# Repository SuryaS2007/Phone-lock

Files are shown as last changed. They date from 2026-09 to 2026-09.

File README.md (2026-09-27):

# Focus Lock

Focus Lock is an ESP32-powered phone lock and active-study timer. RFID tags embedded in physical shells identify saved study durations. The website changes the duration associated with each shell. After scanning a shell, lifting the pencil from its fixed crab-claw rest locks the phone drawer and starts the countdown; returning the pencil pauses it. Reaching zero unlocks the drawer.

## Final prototype flow

```text
Scan RFID shell
-> ESP32 loads that shell's saved duration
-> optionally change/save its duration on the website
-> place pencil on the fixed claws
-> lift pencil
-> drawer locks, buzzer sounds, countdown starts
-> return pencil to pause
-> lift it to resume
-> countdown reaches zero
-> drawer unlocks and buzzer sounds
```

RFID UIDs are hardware identifiers and are not rewritten. The website stores an editable UID-to-duration association in ESP32 nonvolatile memory.

## Hardware roles

- Generic 30-pin ESP32 DevKit V1: controller, Wi-Fi access point, API, timer, and website host.
- Two VL53L0X sensors: detect whether the pencil rests across the stationary claws.
- RC522: reads the RFID tag inside a shell and selects its duration.
- SG90 on GPIO26: locks and unlocks the phone drawer.
- SG90 on GPIO25: optionally sways the crab while active study time is counting.
- TM1637 on GPIO14/GPIO13: physical countdown only.
- LCD1602 at I2C address `0x27`: displays the crab-eye graphic.
- Passive buzzer on GPIO17: start and completion sounds.
- There is no phone-box sensor, reward system, or shell dispenser.

Servo features, shake motion, and buzzer output are disabled by default until their hardware is safely powered and calibrated.

## Website

While connected to the ESP32 `Focus-Lock` access point, open `/servo-test.html` for the development-only lock-servo calibration controls. The page supports direct position commands, repeated sequences, emergency detach, and persistent lock/unlock angle settings.

The beach-themed site is served by the ESP32 at `http://192.168.4.1` on its open `Focus-Lock` Wi-Fi network. It displays the timer and state, shows the last scanned shell UID, edits that shell's duration, provides short developer demos, and plays a user-selected local music file.

## Main API

- `GET /status`: timer, pencil, RFID, sensor, servo, and selected-shell status.
- `GET /shells`: saved shell UID-to-duration mappings.
- `POST /shell`: save `{ "uid": "A1B2C3D4", "duration": 1800 }`.
- `POST /start`: developer demo duration in seconds.
- `POST /reset`: cancel and safely unlock.

Times are seconds. Up to 12 shell mappings and durations up to eight hours are supported.

## PlatformIO

```ini
platform = espressif32@6.12.0
board = esp32doit-devkit-v1
framework = arduino
```

Use PlatformIO **Upload** for firmware and **Upload Filesystem Image** for the website. The build script copies the browser assets into LittleFS automatically.

## Important files

```text
platformio.ini                      PlatformIO environment and libraries
firmware/src/main.cpp               ESP32 firmware
firmware/include/PinConfig.h        GPIO allocation
firmware/include/HardwareConfig.h   calibration and feature flags
firmware/scripts/sync_web.py        browser-to-LittleFS asset sync
index.html and src/                 website
HARDWARE_TRAINING.md                wiring and calibration procedure
PROJECT_LOG.md                      decisions and change history
```

## Power warning

SG90 servos require 4.8-6 V; regulated 5 V is the target. Do not power them from ESP32 3.3 V. The rectangular 9 V battery and breadboard regulator are not a dependable servo source. During development, power the ESP32 over USB and use an adequate regulated 5 V servo supply with its ground connected to ESP32 ground.

If the LCD1602 I2C backpack is powered at 5 V, verify that its SDA/SCL pull-ups do not expose ESP32 pins to 5 V; use 3.3 V operation or proper level shifting as required.

Apply the same caution to the TM1637 module: verify whether the actual board operates at 3.3 V or add suitable level shifting before using a 5 V-powered module with 3.3 V ESP32 GPIO.

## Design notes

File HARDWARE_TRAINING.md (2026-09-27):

# Focus Lock hardware training

Work through these stages in order. Keep `SERVO_ENABLED`, `SHAKE_SERVO_ENABLED`, and `BUZZER_ENABLED` false until each component is tested safely.

## 1. Power safely

```text
Computer USB -> ESP32
ESP32 3V3 -> VL53L0X and RC522 power
Regulated 5V -> SG90 red wires
5V supply ground -> servo grounds AND ESP32 GND
```

Do not use the rectangular 9 V battery as the dependable servo source. SG90 voltage must remain within 4.8-6 V; use regulated 5 V.

## 2. Wire the pencil sensors

```text
Both SDA    -> GPIO21
Both SCL    -> GPIO22
Both VIN    -> 3V3
Both GND    -> GND
Left XSHUT  -> GPIO32
Right XSHUT -> GPIO33
```

The claws do not move. Mount one sensor under each side of the pencil rest. Firmware assigns the sensors I2C addresses `0x30` and `0x31` after every boot.

## 3. Upload the safe base

1. Build and upload the `esp32doit-devkit-v1` environment.
2. Run **Upload Filesystem Image**.
3. Open Serial Monitor at 115200 baud.
4. Confirm both pencil sensors and RC522 initialize.

## 4. Calibrate pencil presence

Serial Monitor prints:

```text
PENCIL_RAW left=42 right=45 removed=false
```

Record ten readings with the pencil resting and ten with it removed. Put the halfway values in `HardwareConfig.h`:

```cpp
LEFT_PENCIL_THRESHOLD_MM = ...;
RIGHT_PENCIL_THRESHOLD_MM = ...;
```

If readings are lower when the pencil is present, keep `PENCIL_PRESENT_WHEN_DISTANCE_LESS = true`; otherwise change it to `false`.

The firmware considers the pencil removed only when both sensors report it absent for at least 350 ms. Returning it over either sensor pauses the timer.

## 5. Train RFID shell durations

Wire the RC522 using the pins in `PinConfig.h`, restart, and connect to the open `Focus-Lock` Wi-Fi network.

1. Open `http://192.168.4.1`.
2. Scan one shell tag.
3. Confirm its UID appears on the website.
4. Enter a duration and select **Save shell**.
5. Scan another shell and give it a different duration.
6. Restart the ESP32 and verify each saved duration remains.

The tag UID is not changed; only its stored duration association changes.

## 6. Test the timer without servos

1. Scan a configured shell or choose a 10-second demo.
2. Rest the pencil across the claws.
3. Lift the pencil and confirm the countdown begins.
4. Return it and confirm the countdown pauses.
5. Lift it again and confirm the timer reaches zero.
6. Confirm the TM1637 shows remaining `MM:SS`.

Verify the TM1637 module's logic voltage before connection. Prefer 3.3 V operation if the module is reliable there; otherwise use appropriate level shifting for its CLK/DIO signals.

## 7. Calibrate the lock SG90

For an unloaded bench test, `SERVO_CYCLE_TEST_MODE` slowly moves the lock servo on GPIO26 from 90 degrees to 0 degrees and back to 90 degrees three times, then detaches the servo signal. Physical clockwise/counterclockwise direction depends on servo mounting. Keep this mode disabled during normal operation and never run it against a mechanical hard stop.

`SERVO_SWIFT_TEST_MODE` sends direct positions without intermediate steps. The current physical 270 -> 180 -> 270 reference maps to servo commands 90 -> 0 -> 90. All executed tests are recorded in `SERVO_TEST_RUNS.md`.

For normal calibration, connect to the `Focus-Lock` Wi-Fi network and open `http://192.168.4.1/servo-test.html`. The page can move to a direct angle, run repeated position sequences, stop and detach the servo, and save the selected angle as the locked or unlocked position. Saved angles persist in ESP32 nonvolatile memory. Servo controls are rejected while a study session is armed or running.

Remove the horn or disconnect the linkage. Use a regulated 5 V supply with common ground. Set:

```cpp
SERVO_ENABLED = false;
SERVO_CALIBRATION_MODE = true;
```

Upload and send `+` or `-` in Serial Monitor to move five degrees at a time. Record safe unlock and lock angles, then set:

```cpp
SERVO_UNLOCK_ANGLE = ...;
SERVO_LOCK_ANGLE = ...;
SERVO_CALIBRATION_MODE = false;
SERVO_ENABLED = true;
```

Stop immediately if the servo stalls, buzzes continuously, heats up, or pushes against a hard stop.

## 8. Add buzzer and shake servo

The buzzer code assumes a passive buzzer on GPIO17. After verifying its type and wiring, set `BUZZER_ENABLED = true`.

The second SG90 uses GPIO25. Calibrate safe left, center, and right angles before setting `SHAKE_SERVO_ENABLED = true`. When enabled, it sways only during `LOCKED_STUDYING` and centers while paused or complete.

## 9. LCD1602 eyes

The base assumes an I2C-backpack LCD1602 at address `0x27` on GPIO21/GPIO22. If it does not respond, run an I2C scan; common alternatives include `0x3F`. Verify safe I2C logic voltage before using a 5 V backpack.

Connect the four I2C-backpack pins as follows:

| LCD1602 backpack | ESP32 |
| --- | --- |
| GND | GND |
| VCC | Safe supply for the specific backpack; verify its logic voltage |
| SDA | GPIO21 (shared with the VL53L0X sensors) |
| SCL | GPIO22 (shared with the VL53L0X sensors) |

The integrated firmware now animates center, left, right, blink, surprised, happy, and sleeping eyes. The expressions respond to the Focus Lock state: selecting a shell shows surprised eyes, a paused timer sleeps, active study uses the calm look/blink loop, and completion shows happy eyes.

Do not connect the LCD using the earlier six-wire prototype assignment `(23, 22, 21, 19, 18, 5)`. Those pins conflict with the RC522 and VL53L0X hardware. The main firmware uses the I2C backpack so the LCD shares only GPIO21/GPIO22.

## 10. Acceptance test

Repeat at least ten times:

```text
Scan shell -> duration loads -> pencil rests -> pencil lifts
-> lock and start sound -> countdown runs -> pencil returns
-> countdown pauses -> pencil lifts -> countdown completes
-> unlock and completion sound
```

Test with a nonvaluable object before placing a phone inside, and retain a manual release.

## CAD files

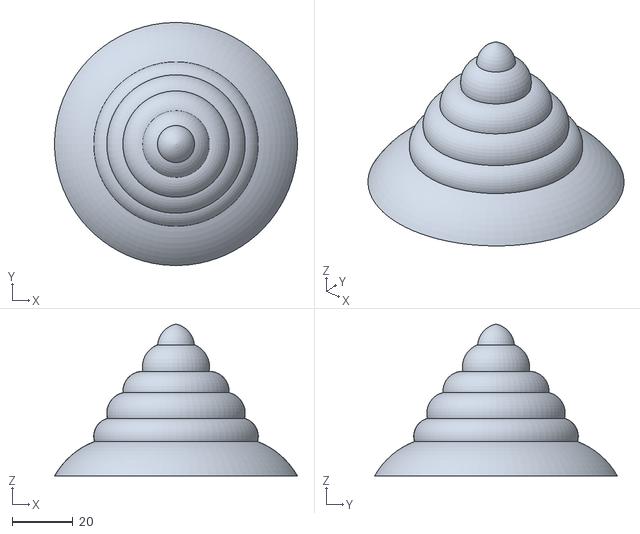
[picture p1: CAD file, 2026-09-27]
printable_stls/big_shell.STL
80.0 x 79.9 x 50.0

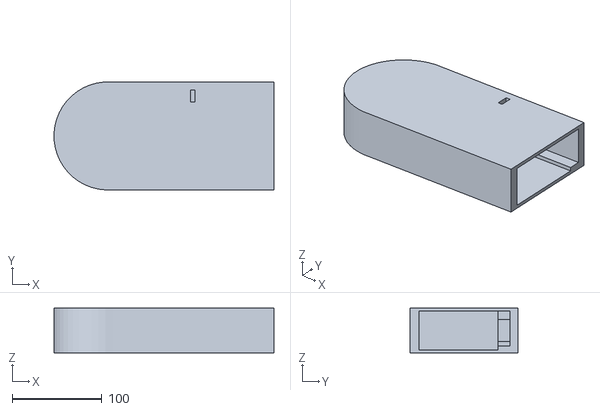
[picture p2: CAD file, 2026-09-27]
printable_stls/base_stand.STL
245.1 x 120.1 x 50.0

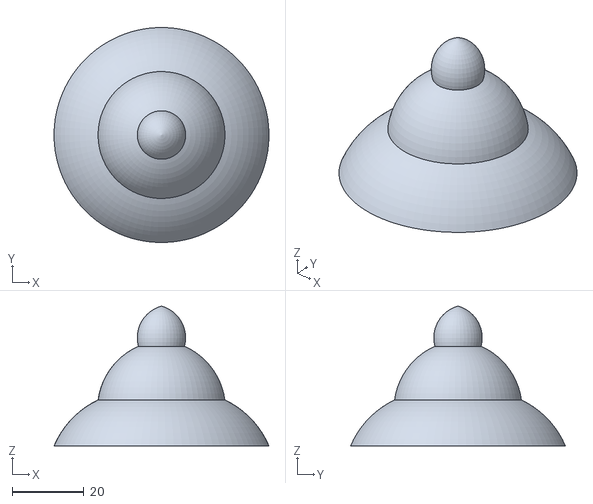
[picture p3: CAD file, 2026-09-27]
printable_stls/small_shell.STL
60.0 x 60.0 x 39.0

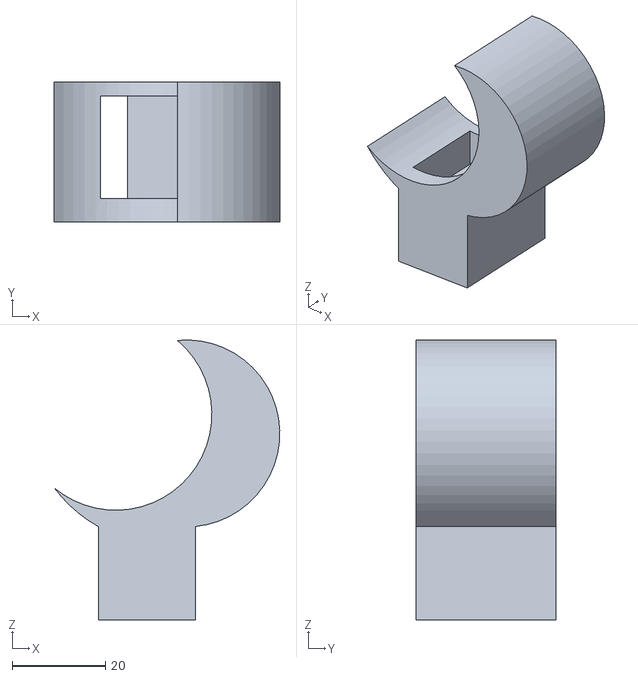
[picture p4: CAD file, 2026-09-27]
printable_stls/claw_arm.STL
48.2 x 30.0 x 59.9

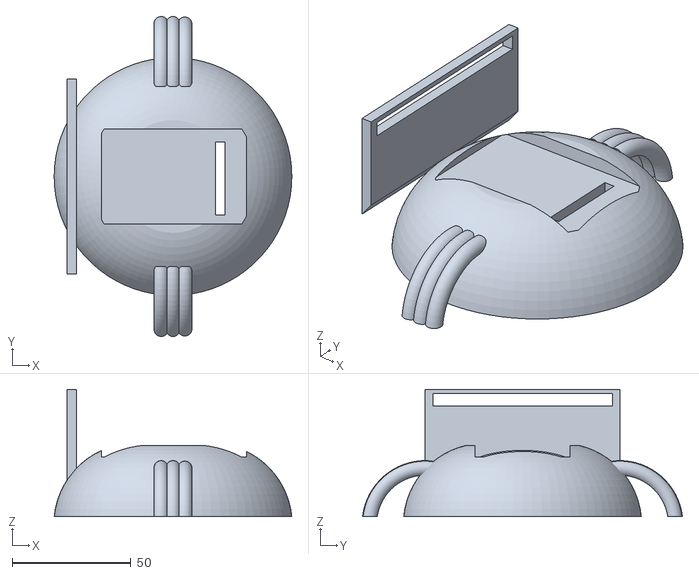
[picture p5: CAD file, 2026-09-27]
printable_stls/body_print.STL
100.0 x 134.6 x 53.5

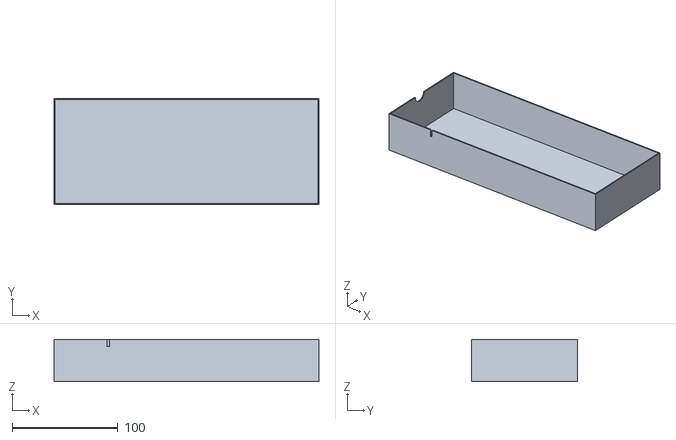
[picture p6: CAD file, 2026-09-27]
printable_stls/drawer_base.STL
250.0 x 100.0 x 40.0

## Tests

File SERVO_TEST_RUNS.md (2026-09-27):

# Focus Lock servo test runs

This file records physical lock-servo tests performed on GPIO26. The servo uses an external regulated 5 V supply with a ground shared with the ESP32.

## Angle notation

The SG90 control command accepts angles from 0 to 180 degrees. For the current mechanical orientation, the team's physical reference labels map as follows:

| Physical reference | Servo command |
| --- | ---: |
| 270 degrees | 90 degrees |
| 180 degrees | 0 degrees |

Physical clockwise/counterclockwise direction depends on which side of the servo is viewed and how its horn is installed.

## 2026-09-26 — Connection and small-movement test

- Board detected as a CP2102 device on COM4 after installing its Windows driver.
- Servo signal: GPIO26.
- Commands: 90 -> 95 -> 100 -> 105 -> 110 -> 105 -> 100 -> 95 -> 90 degrees.
- Result: upload and commands succeeded; user confirmed that the servo moved.
- Firmware was restored with calibration mode disabled.

## 2026-09-26 — Slow three-cycle test

- Commands: 90 -> 0 -> 90 degrees.
- Repetitions: three.
- Motion: smooth 1-degree steps with a 15 ms delay per step.
- End state: 90 degrees, followed by detaching the servo signal.
- Firmware upload completed and automatic test mode was disabled afterward.

## 2026-09-26 — Swift physical 270/180/270 test

- Physical sequence: 270 -> 180 -> 270 degrees.
- Servo command sequence: 90 -> 0 -> 90 degrees.
- Motion: direct position commands with no intermediate 1-degree steps.
- Result: firmware built and uploaded successfully; sequence executed once. Physical movement confirmation is pending from the user.
- Safe restoration: automatic swift test mode was disabled after execution and normal firmware was re-uploaded.

## Reusable browser test controller

- Page: `http://192.168.4.1/servo-test.html` while connected to `Focus-Lock` Wi-Fi.
- Supports direct positions, presets, repeated direct-position sequences, and emergency detach.
- Supports saving calibrated locked and unlocked angles in ESP32 nonvolatile memory.
- Test controls are blocked while a study session is armed or running.
- The page is controlled by `DEVELOPER_TOOLS_ENABLED` in `HardwareConfig.h`.

## 2026-09-26 — Direct firmware fallback test

- Reason: browser pages still reported offline, so the website was bypassed.
- Physical sequence: 270 -> 180 -> 270 degrees.
- Servo command sequence: 90 -> 0 -> 90 degrees on GPIO26.
- Motion: direct commands with no stepping.
- Firmware upload completed, the sequence ran once, and automatic test mode was disabled afterward.

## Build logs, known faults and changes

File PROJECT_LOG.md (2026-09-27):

# Focus Lock — Project Work Log

This document is the living record of work performed on **Focus Lock**. Update it whenever code, configuration, architecture, behavior, dependencies, documentation, or hardware integration changes.

## Project Goal

Focus Lock is a hackathon project built around an ESP32, two light sensors, and a servo-controlled phone drawer. A user chooses an active study-time goal, locks their phone, and earns access to it by studying. Active study time accumulates only while the pencil is picked up; putting the pencil down pauses the timer. Reaching the goal unlocks the phone.

The first milestone is a fully simulated software system. Real ESP32 sensor and servo behavior will replace the simulation later through a hardware abstraction layer.

## Required Core Flow

1. Phone inserted.
2. User starts a session.
3. Phone drawer locks.
4. Pencil picked up.
5. Active-study timer runs.
6. Pencil put down.
7. Timer pauses without resetting.
8. Pencil picked up again.
9. Timer continues from its accumulated value.
10. Active-study goal is reached.
11. Phone drawer unlocks.

## Scope

### In scope

- A clean, simple web frontend.
- Simulated phone, pencil, and servo controls.
- Session states: `IDLE`, `READY`, `LOCKED_PAUSED`, `LOCKED_STUDYING`, and `COMPLETE`.
- Timestamp-based active-time accounting.
- A fast 10–30 second developer demo mode.
- A hardware abstraction with the conceptual operations:
  - `isPhonePresent()`
  - `isPencilPresent()`
  - `lockPhone()`
  - `unlockPhone()`
- Mock API boundaries compatible with eventual ESP32 communication:
  - `GET /status`
  - `POST /start`
- Documentation for running, simulation, project structure, and later hardware integration.

### Explicitly out of scope

- RFID reader
- Crab mechanism
- Coin dispenser
- LED effects
- Authentication or user accounts
- Databases or cloud infrastructure
- Statistics or streaks
- Other bonus features

## Expected State Behavior

| Condition or event | Resulting state | Timer | Lock |
|---|---|---|---|
| No phone is present | `IDLE` | Stopped | Unlocked |
| Phone is inserted, no session started | `READY` | Stopped | Unlocked |
| Session starts with pencil down | `LOCKED_PAUSED` | Paused | Locked |
| Pencil is picked up during session | `LOCKED_STUDYING` | Running | Locked |
| Pencil is put down during session | `LOCKED_PAUSED` | Paused, accumulated time retained | Locked |
| Active time reaches target | `COMPLETE` | Stopped at goal | Unlocked |

## Planned User Interface

- Project name: Focus Lock
- Phone status: `DETECTED` / `NOT DETECTED`
- Pencil status: `PICKED UP` / `PUT DOWN`
- Lock status: `LOCKED` / `UNLOCKED`
- Study-duration input in minutes
- Start Session button
- Active study time
- Remaining study time
- Display status: `READY`, `STUDYING`, `PAUSED`, or `COMPLETE`
- Clearly separated **DEV / SIMULATION** controls for:
  - inserting/removing the phone
  - picking up/putting down the pencil
  - optionally locking/unlocking the simulated servo

## Architecture Notes

- Application/session logic must not directly depend on GPIO, sensors, or servo implementation details.
- Simulation and eventual ESP32 implementations should conform to the same hardware interface.
- Timer correctness must be based on timestamps. Visual refresh intervals may update the screen but must not be the authoritative elapsed-time source.
- Networking should stay minimal. Mock API behavior should preserve a clean seam for a later ESP32-backed implementation.
- The implementation should favor a small, readable hackathon stack and avoid unnecessary abstractions.

## Repository Baseline

Recorded on **2026-09-25**:

- Workspace inspected at `C:\Phone Lock`.
- No existing project files were found.
- The project specification was supplied as an attached text file.
- No application architecture or framework has been selected or created yet.

## Change Log

### 2026-09-26 — Independent VL53L0X detection

- Updated startup diagnostics to check both GPIO32 and GPIO33 XSHUT paths even when one sensor is missing.
- The serial log now identifies whether only the left or only the right pencil sensor is connected.
- Continuous pencil detection still requires both sensors.

### 2026-09-26 — GPIO17 buzzer bench test

- Added a guarded one-shot buzzer test mode.
- Uploaded and executed a 250 ms, 880 Hz tone on GPIO17.
- Disabled buzzer test mode afterward so it does not repeat on reset.
- Physical sound confirmation is pending from the user.

### 2026-09-26 — Phone connection verified

- Confirmed `http://192.168.4.1/status` works from a phone connected directly to `Focus-Lock`.
- This verifies that the ESP32 access point, DHCP, web server, and `/status` API are functioning.
- The earlier offline behavior was isolated to the laptop's VPN and automatic Wi-Fi switching, not the ESP32, servo wiring, or web application.
- Recommended demo workflow: control Focus Lock from a phone with VPN and mobile-data switching disabled while connected to `Focus-Lock`.

### 2026-09-26 — USB Wi-Fi/HTTP diagnostics

- Added serial logging when devices join or leave the ESP32 access point.
- Added serial logging for static-file, `/status`, and `/servo/status` HTTP requests.
- Made the AP channel and maximum client count explicit and disabled Wi-Fi sleep.
- Added a clear success/failure result for access-point startup.

### 2026-09-26 — Mobile controller connection compatibility

- Replaced `AbortSignal.timeout()` with an `AbortController` timer supported by more mobile browsers.
- Increased the controller request timeout to five seconds and disabled cached API responses.
- Improved offline errors to distinguish a timeout from a failed network request.

### 2026-09-26 — Permanent browser servo calibration tools

- Added a beach-themed `/servo-test.html` control page served by the ESP32.
- Added direct angle movement, presets, configurable repeated sequences, and emergency detach.
- Added persistent locked/unlocked angle storage and connected those values to normal drawer movement.
- Added asynchronous sequence execution so HTTP status and emergency-stop requests remain available.
- Servo tools are guarded by `DEVELOPER_TOOLS_ENABLED` and blocked during study sessions.

### 2026-09-26 — Servo test reference and swift-position test

- Added `SERVO_TEST_RUNS.md` to record executed servo tests and angle mappings.
- Added a guarded direct-position test for physical 270 -> 180 -> 270 movement.
- The direct servo commands are 90 -> 0 -> 90 with no 1-degree stepping.

### 2026-09-26 — Controlled lock-servo cycle test

- Added a guarded `SERVO_CYCLE_TEST_MODE` for the lock servo on GPIO26.
- The bench test moves slowly from 90 degrees to 0 degrees and back three times.
- It finishes at 90 degrees and detaches the servo signal.
- The mode is disabled during normal operation.

### 2026-09-26 — Final interaction model corrected and implemented

**Corrected requirements**

- The crab claws are stationary. The pencil rests across them; removing the pencil starts or resumes active study time, and returning it pauses.
- RFID tags are embedded in shells. Each immutable tag UID maps to an editable duration stored in ESP32 nonvolatile memory.
- The website scans/displays the active shell and changes its associated duration; RFID is not a reward or unlock mechanism.
- Reaching zero unlocks the phone drawer.
- TM1637 is the physical countdown display only. LCD1602 displays the crab eyes.
- There is no reward or shell dispenser.
- The second SG90 sways the crab laterally while studying.
- A buzzer indicates session start and completion. There is still no sensor inside the phone cabinet.
- SG90 supply must remain within 4.8-6 V, with regulated 5 V preferred.

**Implementation changes**

- Reworked the ESP32 state flow to `WAITING_FOR_SHELL`, `ARMED`, `LOCKED_PAUSED`, `LOCKED_STUDYING`, and `COMPLETE`.
- Added RC522 scanning and persistent storage for up to 12 UID-duration mappings.
- Added `GET /shells` and `POST /shell` and retained developer start/reset routes.
- Reworked the website into a scanned-shell duration editor.
- Changed sensor logic from claw movement to stationary pencil presence/removal.
- Added TM1637 countdown output, an LCD1602 I2C eye-display driver, passive-buzzer tones, and safely disabled second-servo sway behavior.
- Assigned GPIO17 to the buzzer and GPIO25 to the shake servo.
- Rewrote `README.md` and `HARDWARE_TRAINING.md` around the corrected design.

**Safety defaults**

- Lock servo, shake servo, and buzzer remain disabled until their physical calibration/type checks are complete.
- LCD1602 defaults to I2C address `0x27`; power and pull-up voltage must be verified.

**Verification**

- Corrected firmware compiles for `esp32doit-devkit-v1` with RC522 and TM1637 libraries.
- Build uses 46,360 bytes RAM (14.1%) and 877,705 bytes application flash (67.0%) before the final browser/documentation-only changes.

### 2026-09-26 — Safe ESP32 firmware base implemented

**Changes**

- Added the Arduino firmware entry point with dual VL53L0X XSHUT/address initialization, filtered claw state, timestamp-based session timing, SG90 hooks, safe startup behavior, Wi-Fi access-point mode, HTTP API routes, and LittleFS website serving.
- Added `HardwareConfig.h`; servo output defaults to disabled until physical calibration is complete.
- Added build-time synchronization of browser assets into the firmware filesystem image.
- Added 10/20/30-second website demo buttons and sensor-readiness handling.
- Added `HARDWARE_TRAINING.md` with wiring, sensor threshold training, safe servo calibration, filesystem upload, and full-flow validation instructions.
- Pinned PlatformIO Espressif32 to `6.12.0` because the initially resolved `7.1.3` Arduino package lacked its required board variants.
- Removed deferred RFID and teammate-owned TM1637 libraries from the base dependency list; each feature can add its exact library when integrated.

**Verification**

- PlatformIO firmware build passes for `esp32doit-devkit-v1` using Arduino.
- Firmware uses 45,736 bytes RAM (14.0%) and 854,085 bytes flash (65.2%).
- LittleFS image builds successfully with the complete website module tree.
- Hardware upload and physical behavior remain untested until the board and safely powered components are connected.

### 2026-09-26 — Claw sensing and power plan corrected

**New clarifications**

- There is no phone sensor inside the box.
- Both VL53L0X sensors are mounted at the crab claws and measure claw position. When the pencil is lifted and the claws rise, active study timing begins; returning the pencil/claws pauses it.
- Starting a session no longer requires a `phonePresent` reading. Pressing Start commands the lock and begins the session in studying or paused state based on claw position.
- The TM1637 forms the crab eyes. A teammate owns its implementation and will push it separately; preserve GPIO14/GPIO13 and integrate rather than overwrite their work.
- Two SG90 servos are available, but the second servo shell dispenser remains a later phase.
- The photographed breadboard supply is an ELEGOO Power MB V2 intended to receive the available 9 V battery through its barrel input.

**Power decision**

- Do not rely on a rectangular 9 V battery for SG90 servo power. Use ESP32 USB power during development and a separate regulated 5 V servo supply with common ground. The 9 V/breadboard module may be used only for low-current experiments after verifying jumper voltages and polarity.

**Tooling**

- Installed the official PlatformIO IDE VS Code extension v3.3.4 and its Microsoft C++ tools dependency.

**Files changed**

- Renamed the two VL53L0X definitions in `PinConfig.h` to left/right claw sensors.
- Removed the website's `phonePresent` requirement for enabling Start.
- Updated `README.md` and `PROJECT_LOG.md`.

### 2026-09-26 — Two-sensor demo architecture finalized

**Hardware evidence and decisions**

- Photos confirm a classic 30-pin ESP32/ESP-WROOM-32 DevKit-style board compatible with the selected PlatformIO target. The photographed connector appears to be Micro-USB rather than USB-C; this does not change firmware targeting.
- Reallocated the two available VL53L0X sensors: one detects the pencil and one detects the phone. This supersedes the earlier two-sided pencil detection and proposed third sensor.
- Pencil presence will rely on careful placement and debounce/filtering from one distance sensor.
- Two SG90 servos are available. SG90 #1 is the phone lock on GPIO26. SG90 #2 and GPIO25 are reserved for a future shell dispenser; dispenser behavior is deferred.
- When the dispenser phase is implemented, the simplest RFID policy is selected: any readable tag may claim one shell only after a completed session, and the reward is marked claimed to prevent repeats.
- RFID never overrides an active session or unlocks the phone.
- No buzzer is included.
- The demo access point will be open and named `Focus-Lock`; a password can be added later if interference or unauthorized control becomes a concern.
- The website may accept flexible durations. The four-digit display uses `MM:SS` under 100 minutes and may use `HH:MM` for longer goals; quick 10/20/30-second modes support demonstrations.
- On session start, timing begins immediately if the pencil is already picked up.
- Loss of phone detection during an active session does not stop or unlock it.
- Startup behavior remains fail-safe unlock.
- Exact lock/unlock and future dispense angles require physical calibration.

**Files changed**

- Updated `firmware/include/PinConfig.h` to use two sensors at addresses `0x30` and `0x31`, freeing GPIO16.
- Updated `README.md` and `PROJECT_LOG.md` with the finalized demo architecture.

### 2026-09-26 — PlatformIO target selected

**Confirmed build environment**

- PlatformIO project environment: `esp32doit-devkit-v1`.
- Framework: Arduino.
- Target: classic 30-pin ESP32/ESP-WROOM-32 DevKit V1 with 3.3 V GPIO logic.
- Firmware source is isolated under `firmware/` so it does not conflict with the existing browser JavaScript under `src/`.
- LittleFS is selected for eventually serving the website directly from the ESP32 access point.

**Changes**

- Added `platformio.ini` with the selected board/framework and planned hardware libraries.
- Added `firmware/include/PinConfig.h` with confirmed pins, proposed third VL53L0X XSHUT on GPIO16, runtime I2C addresses, and GPIO25 reserved for the unselected dispenser actuator.

**Tooling note**

- PlatformIO CLI is not currently installed or available on this machine's PATH, so firmware compilation cannot yet be verified locally.

### 2026-09-26 — Hardware behavior decisions clarified

**Confirmed decisions**

- Controller: generic 30-pin classic ESP32/ESP-WROOM-32 DevKit V1, built as `DOIT ESP32 DEVKIT V1` or equivalent `ESP32 Dev Module`, using 3.3 V GPIO logic.
- Phone presence will use a distance sensor rather than RFID.
- Both existing VL53L0X sensors must detect the pencil for it to count as put down.
- Because those two sensors are allocated to the pencil, continuous phone detection requires a third distance sensor or a reallocation of an existing sensor.
- RC522 purpose: trigger the crab's shell-dispensing action, not phone detection or session override.
- No buzzer will be used; remove GPIO25 buzzer behavior from the firmware plan.
- If the pencil is already picked up when a session starts, active time begins immediately.
- Loss of phone-presence detection during a locked session does not stop or unlock the session; it should continue and may expose a warning status.
- On ESP32 startup or power restoration, unlock the phone for prototype safety.
- RFID does not override or unlock an active study session.
- The ESP32 will create its own Wi-Fi access point and serve the website itself. This avoids dependence on venue Wi-Fi and removes cross-origin API configuration.
- Demo timing will support short second-based sessions; the physical four-digit display will use `MM:SS` with a practical maximum of `99:59`.

**Still unresolved**

- Exact module photos/pin labels have not yet been supplied.
- Servo model, external 5 V supply rating, and mechanical lock design are unknown.
- TM1637 operation at 3.3 V still needs testing; 5 V operation may require level shifting.
- Shell dispenser mechanism and its actuator/driver are not specified.
- The third phone-distance sensor and its XSHUT pin must be added to the wiring plan if it is another VL53L0X.

### 2026-09-26 — Hardware architecture revised for selected parts

**Selected hardware and pins**

- RC522 RFID over SPI: CS 5, SCK 18, MOSI 23, MISO 19, RST 27.
- Two VL53L0X sensors on I2C SDA 21/SCL 22, with XSHUT on 32 and 33.
- TM1637 display on CLK 14/DIO 13.
- Externally powered servo signal on GPIO 26.
- Passive buzzer signal on GPIO 25.

**Architecture decisions and cautions**

- The ESP32 remains authoritative for sensors, session state, active-time accounting, display, buzzer, and servo safety; the website remains a remote control/status view.
- The two identical VL53L0X devices require sequential XSHUT initialization and different runtime I2C addresses after every boot.
- The servo uses a separate regulated 5 V supply with its ground joined to ESP32 ground.
- Prefer powering the TM1637 module at 3.3 V if the actual module operates reliably; otherwise add bidirectional 3.3/5 V level shifting rather than exposing ESP32 pins to 5 V pull-ups.
- A bare piezo buzzer can be GPIO-driven; a magnetic/high-current buzzer requires a transistor driver.
- The listed pair of distance sensors is allocated to pencil/claw sensing, leaving continuous phone-presence detection unresolved. RFID can identify a tag but should not automatically be assumed to provide reliable continuous presence near a phone without physical testing.

**Recommended integration order**

1. ESP32 upload and serial diagnostics.
2. Shared I2C bus and dual-sensor address assignment.
3. Pencil-presence decision from both distance readings.
4. TM1637 countdown display.
5. Passive buzzer tones.
6. Separately powered unloaded servo and angle calibration.
7. RC522 read testing and phone-presence strategy validation.
8. State machine and timestamp timer.
9. HTTP status/start API and website connection.
10. Enclosure installation, recalibration, and repeated safety tests.

### 2026-09-25 — Beach theme, countdown, and local music

**Request**

Give the website a simple beach/crab theme, add background music during study, count down, and animate the waves slowly.

**Changes**

- Changed the main clock to show `targetTime - activeTime` from ESP32 status responses.
- Added a soft sky, sand, ocean, clouds, crab accents, and slowly moving CSS waves.
- Added a private local-audio picker with looping play/pause and volume controls.
- Added reduced-motion support that stops decorative animation when requested by the operating system.
- Kept the page free of image and audio dependencies; visuals are CSS and the user supplies their own music.

**Files changed**

- Updated `index.html`, `src/app.js`, `src/styles.css`, `README.md`, and `PROJECT_LOG.md`.

**Known limitations / follow-up**

- Browsers require an explicit user action before audio playback; a selected soundtrack cannot autoplay on session start unless the user has already interacted with playback.

### 2026-09-25 — Website changed to microcontroller timer remote

**Request**

Make the website contain only the time controls and communicate with the microcontroller.

**Approach / decisions**

- Moved ownership of sensor readings, lock state, session state, and timer calculation to the ESP32 contract.
- Reduced the browser to a thin REST client that polls status and sends session starts.
- Kept the controller URL in one configuration file.

**Changes**

- Removed all simulation and hardware controls from the webpage.
- Simplified the interface to active time, progress, duration, Start, status, and connectivity.
- Added `MicrocontrollerApi` with three-second timeouts and useful offline errors.
- Added 500 ms polling of `GET /status` and `POST /start` with duration in seconds.
- Start is disabled while disconnected, during an active session, or when the controller reports no phone.

**Files changed**

- Replaced `index.html`, `src/app.js`, and `src/styles.css` with the thin-controller UI.
- Added `src/api/MicrocontrollerApi.js`.
- Updated `src/config.js`, `README.md`, and `PROJECT_LOG.md`.

**Known limitations / follow-up**

- ESP32 firmware must implement the documented routes and CORS headers.
- The configured hostname must resolve on the user's local network.

**Verification**

- Browser application and API client pass Node syntax checks.
- All 5 retained state-machine reference tests pass.

### 2026-09-25 — Simulated application implemented

**Request**

Code everything possible before hardware is connected.

**Approach / decisions**

- Chose dependency-free HTML, CSS, and JavaScript with a tiny Node static server. This minimizes setup and keeps the hackathon prototype inspectable.
- Made `SessionController` the authoritative state and timing layer.
- Isolated all sensor and servo operations behind `HardwareAdapter`.
- Used elapsed timestamps rather than interval counts for timer accuracy.

**Changes**

- Built the responsive Focus Lock dashboard and status display.
- Added phone and pencil simulation controls plus 10, 20, and 30-second demos.
- Implemented all five required session states, pause/resume accumulation, completion, reset, and automatic unlock.
- Added a mock API facade and a prepared ESP32 HTTP adapter.
- Added a dependency-free static server and automated core logic tests.
- Added setup, architecture, simulation, API, and ESP32 migration documentation.

**Files changed**

- Added `index.html`, `server.js`, `package.json`, `.gitignore`, and `README.md`.
- Added the application under `src/` and automated tests under `test/`.
- Updated `PROJECT_LOG.md`.

**Verification**

- All 5 automated tests pass: IDLE/READY, start/lock, pause/resume accumulation, completion/unlock, invalid start, and simulated phone removal.
- The test command runs the Node test file directly because this workspace blocks the test runner's optional child-process isolation.
- Local-server smoke check passed: `/` and `/src/app.js` both returned HTTP 200, and the page contained the expected Focus Lock title.

**Known limitations / follow-up**

- Real ESP32 firmware, GPIO pin assignments, light thresholds, servo angles, network address, and reconnection behavior require connected hardware.
- Current API is an in-browser facade rather than an HTTP backend; its method and payload shape mirrors the planned endpoints.

### 2026-09-25 — Work log initialized

**Request**

Create a Markdown file that stores everything done and all project changes.

**Changes**

- Added `PROJECT_LOG.md` as the project’s living work and change record.
- Captured the supplied Focus Lock goal, core flow, scope boundaries, required states, planned UI, API direction, timer constraints, and hardware-separation requirements.
- Recorded the empty-repository baseline.

**Files changed**

- Added `PROJECT_LOG.md`.

**Verification**

- Confirmed the repository contained no files before this document was added.
- No build or automated tests were available or applicable.

## Decision Log

| Date | Decision | Reason |
|---|---|---|
| 2026-09-25 | Use `PROJECT_LOG.md` as the canonical ongoing work record. | Keeps implementation history, decisions, validation, and pending work in one visible place. |
| 2026-09-25 | Defer application stack selection until implementation begins. | The current request only asks for the tracking document; recording a framework decision before implementation would be premature. |
| 2026-09-25 | Use dependency-free browser modules and a Node static server. | Keeps setup, debugging, and handoff simple while providing clean modules and tests. |
| 2026-09-25 | Treat `pencilPresent: true` as pencil put down. | A resting pencil covers the light sensor; picking it up means it is absent and active study begins. |
| 2026-09-25 | Reset an active simulated session if the phone is removed. | Preserves the invariant that no detected phone means `IDLE`; real locked hardware should physically prevent this case. |

### 2026-09-26 — Single-sensor pencil buzzer test

**Request**

Test the connected VL53L0X by sounding the buzzer when the pencil moves.

**Changes**

- Added a temporary `PENCIL_BUZZER_TEST_MODE` that accepts either connected sensor.
- A valid object at 50 mm or closer produces a continuous 1000 Hz tone; the buzzer stops immediately when the object is farther away or the reading becomes invalid.
- Preserved the normal two-sensor requirement outside the temporary test mode.

**Files changed**

- `firmware/include/HardwareConfig.h`
- `firmware/src/main.cpp`

**Verification**

- The earlier threshold test compiled and uploaded successfully to the ESP32 on `COM4`; live readings confirmed the right sensor on GPIO33 was working.
- The 50 mm proximity behavior compiled successfully and was uploaded to the ESP32 on `COM4`.

**Known limitations / follow-up**

- Disable `PENCIL_BUZZER_TEST_MODE` after this bench test before restoring normal session behavior.

### 2026-09-26 — Remove proximity buzzer test and check RFID

**Request**

Remove the temporary continuous buzzer behavior and determine whether the RC522 can be detected.

**Changes**

- Removed the 50 mm proximity-buzzer configuration and runtime logic.
- Restored the buzzer to the normal disabled state; start/end sounds remain available for later enablement.
- Restored the normal requirement for both pencil sensors outside dedicated bench tests.

**Verification**

- Firmware compiled and uploaded successfully to the ESP32 on `COM4`.
- Startup reported `RC522: ready (version 0x15)`, confirming the ESP32 can communicate with the RFID reader over SPI.
- No tag UID appeared during the 15-second tag-reading window, so an individual RFID tag has not yet been confirmed.

### 2026-09-26 — Stationary RFID tag polling

**Request**

Scan the tag mounted in Shell 1, save its UID, and identify it as `Shell 1`.

**Changes**

- Changed RFID polling to issue `PICC_WakeupA` every 250 ms so a tag already resting on the RC522 can be detected even if it is in the halted state.
- Retained the one-tag-at-a-time behavior and avoided reselecting the same UID continuously.
- Set the RC522 receiver to maximum gain and added one-second scan-status diagnostics after no UID was returned with Shell 1 present.

**Verification**

- The first upload attempt lost communication at 58% while using 921600 baud.
- Reduced `upload_speed` to 115200; the retry and maximum-gain diagnostic firmware uploaded successfully.
- The RC522 reports ready with version `0x15`, but Shell 1 returned `Timeout in communication` repeatedly, so no UID could be captured or labeled yet.
- A second 15-second maximum-gain scan produced the same timeout; Shell 1 still has no captured UID.
- After restarting, a 10-second empty-reader baseline reported RC522 version `0x15` and repeated `Timeout in communication`, which is the expected no-tag response.
- With a tag then placed on the antenna, a 15-second scan produced the identical timeout response; the RC522 registered no RF response from that tag.
- A subsequent retry produced one `Error in communication` followed by timeouts and no UID; this suggests a possible weak/partial RF response but not a successful tag read.
- A clean 20-second scan with only the bare tag on the antenna produced continuous timeouts and no UID.
- Another 20-second retry again produced only communication timeouts; no UID was detected.
- One final 15-second retry produced only communication timeouts; RFID scanning remains unavailable.
- A non-resetting serial-monitor retry also produced only timeouts, ruling out monitor-triggered ESP32 resets as the cause of the failed tag read.
- Another filtered 15-second live scan returned 15 consecutive RFID communication timeouts and no UID.

### 2026-09-27 — RC522 bidirectional SPI diagnostic

**Request**

Verify whether the ESP32 can send register data to the RC522 and receive register data back, without running the RC522 self-test.

**Changes**

- Added eight repeated version-register reads.
- Added receiver-gain register round trips using `0x00` and `0x70`, restoring maximum 48 dB gain afterward.
- Added a read of `TxControlReg` to verify that both antenna-driver enable bits are set.
- The diagnostic explicitly reports `self_test=NOT_RUN`.

**Verification**

- Firmware compiled and uploaded successfully on `COM4` at 115200 baud.
- Version register returned `0x15` consistently across all eight reads.
- Gain register round-trip passed: write `0x00`/read `0x00`, then write `0x70`/read `0x70`.
- `TxControlReg` read `0x83`; antenna enable bits were on.
- Output explicitly confirmed `self_test=NOT_RUN`.
- Tag wake-up still returned `STATUS_TIMEOUT`, so digital SPI works but the RF/tag path remains unsuccessful.
- A separate 20-second test using the RFID card also returned continuous `STATUS_TIMEOUT` responses and no UID.
- A 15-second test with the identified low-frequency card returned continuous timeouts, confirming it is not readable by the 13.56 MHz RC522.
- Another card scan produced mostly timeouts plus two generic communication errors, but still no ATQA/UID and therefore no successful read.

### 2026-09-27 — Minimal 1 MHz RC522 isolation test

**Request**

Run the strongest remaining RC522 diagnostic without performing the chip self-test.

**Changes**

- Added a separate `rfid-minimal` PlatformIO environment using 1 MHz SPI.
- Added an RC522-only test program; Wi-Fi, I2C sensors, displays, servos, and buzzer are excluded.
- The test reports eight version reads, bidirectional register round trips, antenna-driver bits, ATQA, status code, and UID.
- The full Focus Lock firmware remains intact and can be restored after the temporary test.

**Verification**

- The minimal firmware compiled and uploaded successfully; flash use was 21.3%.
- At 1 MHz, all eight version reads remained `0x15`.
- Gain register round-trip passed (`0x00` and `0x70`), `TxControlReg` was `0x83`, antenna bits were on, and self-test was not run.
- Eleven consecutive tag wake-up attempts returned status `3` (`STATUS_TIMEOUT`); no ATQA or UID was received.
- The first full-firmware restoration build exposed a duplicate-source filter issue; `platformio.ini` was corrected so each environment compiles only its intended source.
- The full Focus Lock firmware then compiled and was restored successfully to `COM4`.
- A final 20-second scan with one isolated tag after the full firmware restoration returned 19 consecutive `STATUS_TIMEOUT` responses and no UID.

### 2026-09-27 — Manual Shell 1/Shell 2 RFID bypass

**Request**

Hardcode a reliable demo flow that does not depend on the failed RC522 tag scan.

**Changes**

- Disabled RFID operation in demo mode.
- Added manual `SHELL1` and `SHELL2` firmware identities with default durations of 15 and 30 minutes.
- Added `/shell/select` so the website can arm either shell while retaining per-shell saved durations.
- Added Shell 1 and Shell 2 website buttons and removed RFID readiness as a UI requirement.
- Updated pencil sensing so the single connected VL53L0X can run the demo; two sensors remain supported automatically.
- Preserved servo safe mode until the physical lock/unlock angles are finalized.

**Verification**

- Browser JavaScript syntax checks passed.
- All five Node tests passed.
- ESP32 firmware compiled successfully (RAM 14.2%, flash 68.3%).
- Upload is pending because the ESP32 USB serial device disappeared; only the laptop's COM3 port is currently visible.

### 2026-09-27 — Teammate branch and LCD1602 expression integration

**Request**

Bring the teammates' commits into `main` and integrate the crab-eye expression code with the complete firmware.

**Changes**

- Merged the STL files from remote `main`: crab body, claw arm, and drawer base.
- Merged the LCD expression branch while retaining its contributor history.
- Ported center, left, right, blink, happy, surprised, and sleeping custom characters into the real `firmware/src/main.cpp` build.
- Replaced blocking animation delays with a non-blocking state-driven animation so Wi-Fi, sensors, and the countdown continue running.
- Mapped expressions to session behavior: surprised when armed, sleeping while paused, calm animation while waiting/studying, and happy when complete.
- Adapted the prototype from a conflicting six-pin parallel connection to the project's existing LCD1602 I2C driver on GPIO21/GPIO22.
- Removed the unused root-level prototype after porting its behavior and removed its unnecessary `LiquidCrystal` dependency.
- Expanded `HARDWARE_TRAINING.md` with the LCD backpack wiring and pin-conflict warning.

**Verification**

- The combined `esp32doit-devkit-v1` firmware build completed successfully with exit code 0.
- All five website/session-controller tests passed.
- `git diff --check` reported no whitespace errors.

## Pending Work

- Connect the physical sensors and determine reliable light thresholds.
- Define ESP32 GPIO pins and locked/unlocked servo angles.
- Implement ESP32 firmware HTTP endpoints.
- Add polling, connection-state feedback, and retry handling for ESP32 mode.
- Validate servo fail-safe behavior on power loss or network failure.

## Entry Template for Future Changes

Copy this section for every meaningful unit of work:

```md
### YYYY-MM-DD — Short change title

**Request**

What was requested or what problem was addressed.

**Approach / decisions**

- Important implementation choices and their reasons.

**Changes**

- Concrete behavior, code, configuration, dependency, or documentation changes.

**Files changed**

- `path/to/file` — concise description.

**Verification**

- Commands/tests performed and their outcomes.

**Known limitations / follow-up**

- Anything intentionally incomplete or worth revisiting.
```

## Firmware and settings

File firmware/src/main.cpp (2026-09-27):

#include <Arduino.h>
#include <ArduinoJson.h>
#include <ESP32Servo.h>
#include <LittleFS.h>
#include <MFRC522.h>
#include <Preferences.h>
#include <SPI.h>
#include <TM1637TinyDisplay.h>
#include <VL53L0X.h>
#include <WebServer.h>
#include <WiFi.h>
#include <Wire.h>

#include "HardwareConfig.h"
#include "PinConfig.h"

enum class SessionState {
  WAITING_FOR_SHELL,
  ARMED,
  LOCKED_PAUSED,
  LOCKED_STUDYING,
  COMPLETE
};

struct ShellSetting {
  String uid;
  uint32_t durationSeconds;
};

class Lcd1602I2c {
 public:
  explicit Lcd1602I2c(uint8_t address) : address_(address) {}

  void begin() {
    delay(50);
    writeNibble(0x03, false); delay(5);
    writeNibble(0x03, false); delayMicroseconds(150);
    writeNibble(0x03, false);
    writeNibble(0x02, false);
    command(0x28); // 4-bit, 2 line, 5x8 font
    command(0x0C); // display on, cursor off
    command(0x06); // left-to-right entry
    clear();
  }

  void clear() { command(0x01); delay(2); }

  void printLine(uint8_t row, const String &text) {
    command(row == 0 ? 0x80 : 0xC0);
    String padded = text.substring(0, 16);
    while (padded.length() < 16) padded += ' ';
    for (char character : padded) send(static_cast<uint8_t>(character), true);
  }

  void createChar(uint8_t slot, const uint8_t glyph[8]) {
    command(static_cast<uint8_t>(0x40 | ((slot & 0x07) << 3)));
    for (uint8_t row = 0; row < 8; ++row) send(glyph[row], true);
  }

  void setCursor(uint8_t column, uint8_t row) {
    command(static_cast<uint8_t>((row == 0 ? 0x80 : 0xC0) + min(column, static_cast<uint8_t>(15))));
  }

  void writeChar(uint8_t character) { send(character, true); }

 private:
  static constexpr uint8_t BACKLIGHT = 0x08;
  static constexpr uint8_t ENABLE = 0x04;
  uint8_t address_;

  void command(uint8_t value) { send(value, false); }

  void send(uint8_t value, bool data) {
    writeNibble(value >> 4, data);
    writeNibble(value & 0x0F, data);
  }

  void writeNibble(uint8_t nibble, bool data) {
    const uint8_t output = static_cast<uint8_t>((nibble << 4) | BACKLIGHT | (data ? 0x01 : 0x00));
    Wire.beginTransmission(address_);
    Wire.write(output | ENABLE);
    Wire.endTransmission();
    delayMicroseconds(1);
    Wire.beginTransmission(address_);
    Wire.write(output & ~ENABLE);
    Wire.endTransmission();
    delayMicroseconds(50);
  }
};

enum class EyeExpression {
  CENTER,
  LEFT,
  RIGHT,
  BLINK,
  HAPPY,
  SURPRISED,
  SLEEP
};

// LCD1602 custom characters adapted from the teammate eye-expression prototype.
const uint8_t CENTER_TOP[8] = {
  0b01110, 0b10001, 0b10001, 0b10001, 0b10001, 0b10101, 0b10101, 0b10101
};
const uint8_t CENTER_BOTTOM[8] = {
  0b10101, 0b10101, 0b10101, 0b10001, 0b10001, 0b10001, 0b10001, 0b01110
};
const uint8_t LEFT_TOP[8] = {
  0b11110, 0b10001, 0b10001, 0b10001, 0b10001, 0b11001, 0b11001, 0b11001
};
const uint8_t LEFT_BOTTOM[8] = {
  0b11001, 0b11001, 0b11001, 0b10001, 0b10001, 0b10001, 0b10001, 0b01110
};
const uint8_t RIGHT_TOP[8] = {
  0b01111, 0b10001, 0b10001, 0b10001, 0b10001, 0b10011, 0b10011, 0b10011
};
const uint8_t RIGHT_BOTTOM[8] = {
  0b10011, 0b10011, 0b10011, 0b10001, 0b10001, 0b10001, 0b10001, 0b01110
};
const uint8_t BLINK_TOP[8] = {
  0b00000, 0b00000, 0b00000, 0b00000, 0b00000, 0b11111, 0b11111, 0b00000
};
const uint8_t BLINK_BOTTOM[8] = {
  0b00000, 0b11111, 0b11111, 0b00000, 0b00000, 0b00000, 0b00000, 0b00000
};
const uint8_t HAPPY_TOP[8] = {
  0b00000, 0b00000, 0b00000, 0b01110, 0b10001, 0b10001, 0b10001, 0b00000
};
const uint8_t HAPPY_BOTTOM[8] = {
  0b00000, 0b00000, 0b00000, 0b00000, 0b00000, 0b00000, 0b00000, 0b00000
};
const uint8_t SURPRISED_TOP[8] = {
  0b01110, 0b10001, 0b10001, 0b10001, 0b10001, 0b10001, 0b10101, 0b10101
};
const uint8_t SURPRISED_BOTTOM[8] = {
  0b10101, 0b10101, 0b10001, 0b10001, 0b10001, 0b10001, 0b10001, 0b01110
};
const uint8_t SLEEP_TOP[8] = {
  0b00000, 0b00000, 0b00000, 0b00000, 0b00000, 0b10001, 0b01110, 0b00000
};
const uint8_t SLEEP_BOTTOM[8] = {
  0b00000, 0b00000, 0b00000, 0b00000, 0b00000, 0b00000, 0b00000, 0b00000
};

WebServer server(80);
VL53L0X leftPencilSensor;
VL53L0X rightPencilSensor;
MFRC522 rfid(Pins::RFID_CS, Pins::RFID_RST);
TM1637TinyDisplay countdownDisplay(Pins::DISPLAY_CLK, Pins::DISPLAY_DIO);
Lcd1602I2c eyeDisplay(HardwareConfig::LCD1602_ADDRESS);
Servo lockServo;
Servo shakeServo;
Preferences preferences;
Preferences servoPreferences;

ShellSetting shells[HardwareConfig::MAX_SHELLS];
size_t shellCount = 0;
String selectedShellUid;
uint32_t selectedDurationSeconds = HardwareConfig::DEFAULT_SHELL_SECONDS;

bool sensorsReady = false;
bool leftSensorReady = false;
bool rightSensorReady = false;
bool rfidReady = false;
bool filesystemReady = false;
bool lockServoAttached = false;
bool shakeServoAttached = false;
bool drawerLocked = false;
int lastReportedApClients = -1;
int savedUnlockAngle = HardwareConfig::SERVO_UNLOCK_ANGLE;
int savedLockAngle = HardwareConfig::SERVO_LOCK_ANGLE;
int currentLockServoAngle = -1;

struct ServoSequenceState {
  bool active = false;
  int outerAngle = 90;
  int innerAngle = 0;
  unsigned int repetitions = 1;
  unsigned int completed = 0;
  unsigned int holdMs = 700;
  unsigned int leg = 0;
  unsigned long changedAt = 0;
};

ServoSequenceState servoSequence;

uint16_t leftDistanceMm = 0;
uint16_t rightDistanceMm = 0;
bool leftReadingValid = false;
bool rightReadingValid = false;
bool pencilRemoved = false;
bool pendingPencilRemoved = false;
bool pencilSeenAfterShellScan = false;
unsigned long pendingPencilChangeAt = 0;
unsigned long lastSensorReadAt = 0;
unsigned long lastDiagnosticAt = 0;
unsigned long lastRfidPollAt = 0;
unsigned long lastRfidDiagnosticAt = 0;
unsigned long lastDisplayUpdateAt = 0;
unsigned long lastShakeAt = 0;
bool shakeDirection = false;
EyeExpression currentEyeExpression = static_cast<EyeExpression>(255);
SessionState lastEyeSessionState = SessionState::COMPLETE;
unsigned long eyeAnimationStartedAt = 0;

SessionState sessionState = SessionState::WAITING_FOR_SHELL;
bool sessionActive = false;
uint32_t targetTimeMs = 0;
uint32_t accumulatedTimeMs = 0;
uint32_t studyingStartedAt = 0;

const char *stateName() {
  switch (sessionState) {
    case SessionState::WAITING_FOR_SHELL: return "WAITING_FOR_SHELL";
    case SessionState::ARMED: return "ARMED";
    case SessionState::LOCKED_PAUSED: return "LOCKED_PAUSED";
    case SessionState::LOCKED_STUDYING: return "LOCKED_STUDYING";
    case SessionState::COMPLETE: return "COMPLETE";
  }
  return "WAITING_FOR_SHELL";
}

uint32_t activeTimeMs() {
  uint32_t active = accumulatedTimeMs;
  if (sessionActive && sessionState == SessionState::LOCKED_STUDYING) active += millis() - studyingStartedAt;
  return targetTimeMs > 0 ? min(active, targetTimeMs) : active;
}

uint32_t remainingSeconds() {
  const uint32_t active = activeTimeMs();
  if (active >= targetTimeMs) return 0;
  return (targetTimeMs - active + 999UL) / 1000UL;
}

void playTone(uint16_t frequency, uint16_t durationMs) {
  if (!HardwareConfig::BUZZER_ENABLED && !HardwareConfig::BUZZER_TEST_MODE) return;
  ledcWriteTone(HardwareConfig::BUZZER_PWM_CHANNEL, frequency);
  delay(durationMs);
  ledcWriteTone(HardwareConfig::BUZZER_PWM_CHANNEL, 0);
}

void playStartSound() { playTone(880, 140); }

void playCompleteSound() {
  playTone(660, 120); delay(60);
  playTone(880, 120); delay(60);
  playTone(1100, 220);
}

void writeLockServo(int angle) {
  if (!lockServoAttached) return;
  currentLockServoAngle = constrain(angle, 0, 180);
  lockServo.write(currentLockServoAngle);
  delay(250);
}

bool attachLockServo() {
  if (lockServoAttached) return true;
  lockServo.setPeriodHertz(50);
  lockServo.attach(Pins::LOCK_SERVO, HardwareConfig::SERVO_MIN_PULSE_US, HardwareConfig::SERVO_MAX_PULSE_US);
  lockServoAttached = lockServo.attached();
  return lockServoAttached;
}

void detachLockServo() {
  servoSequence.active = false;
  if (lockServoAttached) lockServo.detach();
  lockServoAttached = false;
}

void unlockDrawer() {
  if (HardwareConfig::SERVO_ENABLED || HardwareConfig::SERVO_CALIBRATION_MODE) {
    if (attachLockServo()) writeLockServo(savedUnlockAngle);
  }
  drawerLocked = false;
}

void lockDrawer() {
  if (HardwareConfig::SERVO_ENABLED) {
    drawerLocked = attachLockServo();
    if (drawerLocked) writeLockServo(savedLockAngle);
  } else {
    drawerLocked = false;
    Serial.println("[SAFE MODE] Lock requested, but SERVO_ENABLED is false.");
  }
}

void stopShake() {
  if (shakeServoAttached) shakeServo.write(HardwareConfig::SHAKE_CENTER_ANGLE);
}

void updateShake() {
  if (!shakeServoAttached) return;
  if (sessionState != SessionState::LOCKED_STUDYING) {
    stopShake();
    return;
  }
  if (millis() - lastShakeAt < HardwareConfig::SHAKE_INTERVAL_MS) return;
  lastShakeAt = millis();
  shakeDirection = !shakeDirection;
  shakeServo.write(shakeDirection ? HardwareConfig::SHAKE_LEFT_ANGLE : HardwareConfig::SHAKE_RIGHT_ANGLE);
}

bool initializeSensors() {
  pinMode(Pins::LEFT_PENCIL_XSHUT, OUTPUT);
  pinMode(Pins::RIGHT_PENCIL_XSHUT, OUTPUT);
  digitalWrite(Pins::LEFT_PENCIL_XSHUT, LOW);
  digitalWrite(Pins::RIGHT_PENCIL_XSHUT, LOW);
  delay(20);

  digitalWrite(Pins::LEFT_PENCIL_XSHUT, HIGH);
  delay(20);
  leftSensorReady = leftPencilSensor.init();
  if (!leftSensorReady) {
    Serial.println("ERROR: Left pencil VL53L0X was not found.");
  } else {
    leftPencilSensor.setAddress(I2cAddresses::LEFT_PENCIL);
    leftPencilSensor.setTimeout(HardwareConfig::SENSOR_TIMEOUT_MS);
  }

  digitalWrite(Pins::RIGHT_PENCIL_XSHUT, HIGH);
  delay(20);
  rightSensorReady = rightPencilSensor.init();
  if (!rightSensorReady) {
    Serial.println("ERROR: Right pencil VL53L0X was not found.");
  } else {
    rightPencilSensor.setAddress(I2cAddresses::RIGHT_PENCIL);
    rightPencilSensor.setTimeout(HardwareConfig::SENSOR_TIMEOUT_MS);
  }

  if (leftSensorReady) leftPencilSensor.startContinuous(HardwareConfig::SENSOR_PERIOD_MS);
  if (rightSensorReady) rightPencilSensor.startContinuous(HardwareConfig::SENSOR_PERIOD_MS);

  if (!leftSensorReady && !rightSensorReady) {
    Serial.println("ERROR: No pencil VL53L0X sensors were detected.");
    return false;
  }

  if (!leftSensorReady || !rightSensorReady) {
    if (leftSensorReady) Serial.println("Detected only the LEFT pencil sensor through GPIO32 XSHUT.");
    if (rightSensorReady) Serial.println("Detected only the RIGHT pencil sensor through GPIO33 XSHUT.");
    Serial.println("DEMO MODE: The connected sensor will control pencil detection.");
    return true;
  }

  Serial.println("Both pencil sensors initialized at 0x30 and 0x31.");
  return true;
}

bool readingMeansPencilPresent(uint16_t distance, uint16_t threshold) {
  return HardwareConfig::PENCIL_PRESENT_WHEN_DISTANCE_LESS ? distance < threshold : distance > threshold;
}

void updatePencilSensors() {
  const unsigned long now = millis();
  if (!sensorsReady || now - lastSensorReadAt < HardwareConfig::SENSOR_PERIOD_MS) return;
  lastSensorReadAt = now;

  if (leftSensorReady) {
    leftDistanceMm = leftPencilSensor.readRangeContinuousMillimeters();
    leftReadingValid = !leftPencilSensor.timeoutOccurred() && leftDistanceMm < 8190;
  }
  if (rightSensorReady) {
    rightDistanceMm = rightPencilSensor.readRangeContinuousMillimeters();
    rightReadingValid = !rightPencilSensor.timeoutOccurred() && rightDistanceMm < 8190;
  }

  const bool connectedReadingsValid =
    (leftSensorReady || rightSensorReady) &&
    (!leftSensorReady || leftReadingValid) &&
    (!rightSensorReady || rightReadingValid);

  if (connectedReadingsValid) {
    const bool leftPresent = leftSensorReady && leftReadingValid &&
      readingMeansPencilPresent(leftDistanceMm, HardwareConfig::LEFT_PENCIL_THRESHOLD_MM);
    const bool rightPresent = rightSensorReady && rightReadingValid &&
      readingMeansPencilPresent(rightDistanceMm, HardwareConfig::RIGHT_PENCIL_THRESHOLD_MM);
    const bool rawRemoved = !leftPresent && !rightPresent;

    if (rawRemoved != pendingPencilRemoved) {
      pendingPencilRemoved = rawRemoved;
      pendingPencilChangeAt = now;
    } else if (pencilRemoved != pendingPencilRemoved && now - pendingPencilChangeAt >= HardwareConfig::PENCIL_DEBOUNCE_MS) {
      pencilRemoved = pendingPencilRemoved;
      Serial.printf("Pencil: %s\n", pencilRemoved ? "REMOVED / STUDYING" : "RESTING / PAUSED");
    }
  }

  if (HardwareConfig::SENSOR_DIAGNOSTICS && now - lastDiagnosticAt >= 500) {
    lastDiagnosticAt = now;
    Serial.printf("PENCIL_RAW left=%u%s right=%u%s removed=%s\n",
      leftDistanceMm, leftReadingValid ? "" : " INVALID",
      rightDistanceMm, rightReadingValid ? "" : " INVALID",
      pencilRemoved ? "true" : "false");
  }
}

int findShell(const String &uid) {
  for (size_t index = 0; index < shellCount; ++index) if (shells[index].uid == uid) return static_cast<int>(index);
  return -1;
}

void saveShells() {
  JsonDocument document;
  JsonArray array = document.to<JsonArray>();
  for (size_t index = 0; index < shellCount; ++index) {
    JsonObject item = array.add<JsonObject>();
    item["uid"] = shells[index].uid;
    item["duration"] = shells[index].durationSeconds;
  }
  String json;
  serializeJson(document, json);
  preferences.putString("shells", json);
}

void loadShells() {
  preferences.begin("focus-lock", false);
  const String json = preferences.getString("shells", "[]");
  JsonDocument document;
  if (deserializeJson(document, json)) return;
  for (JsonObject item : document.as<JsonArray>()) {
    if (shellCount >= HardwareConfig::MAX_SHELLS) break;
    shells[shellCount].uid = item["uid"].as<String>();
    shells[shellCount].durationSeconds = item["duration"] | HardwareConfig::DEFAULT_SHELL_SECONDS;
    ++shellCount;
  }
}

bool setShellDuration(String uid, uint32_t durationSeconds) {
  uid.toUpperCase();
  int index = findShell(uid);
  if (index < 0) {
    if (shellCount >= HardwareConfig::MAX_SHELLS) return false;
    index = static_cast<int>(shellCount++);
    shells[index].uid = uid;
  }
  shells[index].durationSeconds = durationSeconds;
  saveShells();
  return true;
}

uint32_t durationForShell(const String &uid, bool &configured) {
  const int index = findShell(uid);
  configured = index >= 0;
  if (configured) return shells[index].durationSeconds;
  if (uid == HardwareConfig::MANUAL_SHELL_1_UID) return HardwareConfig::MANUAL_SHELL_1_DEFAULT_SECONDS;
  if (uid == HardwareConfig::MANUAL_SHELL_2_UID) return HardwareConfig::MANUAL_SHELL_2_DEFAULT_SECONDS;
  return HardwareConfig::DEFAULT_SHELL_SECONDS;
}

String readUid() {
  String uid;
  for (byte index = 0; index < rfid.uid.size; ++index) {
    if (rfid.uid.uidByte[index] < 0x10) uid += '0';
    uid += String(rfid.uid.uidByte[index], HEX);
  }
  uid.toUpperCase();
  return uid;
}

void selectShell(const String &uid) {
  if (sessionActive) return;
  bool configured = false;
  selectedShellUid = uid;
  selectedDurationSeconds = durationForShell(uid, configured);
  targetTimeMs = selectedDurationSeconds * 1000UL;
  accumulatedTimeMs = 0;
  sessionState = SessionState::ARMED;
  pencilSeenAfterShellScan = !pencilRemoved;
  Serial.printf("Shell %s selected: %lu seconds (%s).\n", uid.c_str(), selectedDurationSeconds,
    configured ? "saved value" : "default value");
}

void updateRfid() {
  if (!HardwareConfig::RFID_ENABLED || !rfidReady || sessionActive) return;
  const unsigned long now = millis();
  if (now - lastRfidPollAt < 250) return;
  lastRfidPollAt = now;

  byte atqa[2];
  byte atqaSize = sizeof(atqa);
  const MFRC522::StatusCode wakeStatus = rfid.PICC_WakeupA(atqa, &atqaSize);
  if (wakeStatus != MFRC522::STATUS_OK && wakeStatus != MFRC522::STATUS_COLLISION) {
    if (now - lastRfidDiagnosticAt >= 1000) {
      lastRfidDiagnosticAt = now;
      Serial.printf("RFID_SCAN: waiting (%s)\n", rfid.GetStatusCodeName(wakeStatus));
    }
    return;
  }
  if (!rfid.PICC_ReadCardSerial()) return;

  const String uid = readUid();
  if (uid != selectedShellUid) selectShell(uid);
  rfid.PICC_HaltA();
  rfid.PCD_StopCrypto1();
}

void runRfidSpiDiagnostics() {
  Serial.print("RFID_SPI version_reads=");
  for (byte index = 0; index < 8; ++index) {
    if (index) Serial.print(',');
    Serial.printf("%02X", rfid.PCD_ReadRegister(MFRC522::VersionReg));
    delay(2);
  }
  Serial.println();

  rfid.PCD_SetAntennaGain(rfid.RxGain_min);
  const byte minimumGainReadback = rfid.PCD_GetAntennaGain();
  rfid.PCD_SetAntennaGain(rfid.RxGain_max);
  const byte maximumGainReadback = rfid.PCD_GetAntennaGain();
  const byte txControl = rfid.PCD_ReadRegister(MFRC522::TxControlReg);

  const bool registerRoundTripPassed =
    minimumGainReadback == rfid.RxGain_min &&
    maximumGainReadback == rfid.RxGain_max;
  const bool antennaDriversEnabled = (txControl & 0x03) == 0x03;

  Serial.printf(
    "RFID_SPI gain_write_00_read_%02X gain_write_70_read_%02X round_trip=%s tx_control=%02X antenna_bits=%s self_test=NOT_RUN\n",
    minimumGainReadback,
    maximumGainReadback,
    registerRoundTripPassed ? "PASS" : "FAIL",
    txControl,
    antennaDriversEnabled ? "ON" : "OFF");
}

void beginSession() {
  if (selectedShellUid.isEmpty() || targetTimeMs == 0 || sessionActive) return;
  accumulatedTimeMs = 0;
  studyingStartedAt = millis();
  sessionActive = true;
  sessionState = SessionState::LOCKED_STUDYING;
  lockDrawer();
  playStartSound();
  Serial.printf("Session started from shell %s for %lu seconds.\n", selectedShellUid.c_str(), selectedDurationSeconds);
}

void completeSession() {
  accumulatedTimeMs = targetTimeMs;
  sessionActive = false;
  sessionState = SessionState::COMPLETE;
  stopShake();
  unlockDrawer();
  playCompleteSound();
  Serial.println("Session complete. Drawer unlocked.");
}

void updateSession() {
  if (sessionState == SessionState::ARMED) {
    if (!pencilRemoved) pencilSeenAfterShellScan = true;
    if (pencilRemoved && pencilSeenAfterShellScan) beginSession();
    return;
  }
  if (!sessionActive) return;

  if (pencilRemoved && sessionState == SessionState::LOCKED_PAUSED) {
    studyingStartedAt = millis();
    sessionState = SessionState::LOCKED_STUDYING;
  } else if (!pencilRemoved && sessionState == SessionState::LOCKED_STUDYING) {
    accumulatedTimeMs += millis() - studyingStartedAt;
    sessionState = SessionState::LOCKED_PAUSED;
    stopShake();
  }
  if (activeTimeMs() >= targetTimeMs) completeSession();
}

void updateCountdownDisplay() {
  if (!HardwareConfig::TM1637_ENABLED || millis() - lastDisplayUpdateAt < 200) return;
  lastDisplayUpdateAt = millis();
  if (sessionState == SessionState::WAITING_FOR_SHELL) {
    countdownDisplay.showString("----");
    return;
  }
  const uint32_t seconds = remainingSeconds();
  uint16_t displayValue;
  if (seconds < 100UL * 60UL) {
    displayValue = static_cast<uint16_t>((seconds / 60UL) * 100UL + seconds % 60UL);
  } else {
    const uint32_t minutes = (seconds + 59UL) / 60UL;
    displayValue = static_cast<uint16_t>((minutes / 60UL) * 100UL + minutes % 60UL);
  }
  countdownDisplay.showNumberDec(displayValue, 0b01000000, true, 4, 0);
}

void showEyeCharacters(uint8_t topCharacter, uint8_t bottomCharacter) {
  eyeDisplay.setCursor(4, 0);
  eyeDisplay.writeChar(topCharacter);
  eyeDisplay.setCursor(4, 1);
  eyeDisplay.writeChar(bottomCharacter);
  eyeDisplay.setCursor(11, 0);
  eyeDisplay.writeChar(topCharacter);
  eyeDisplay.setCursor(11, 1);
  eyeDisplay.writeChar(bottomCharacter);
}

void setEyeExpression(EyeExpression expression) {
  if (!HardwareConfig::LCD1602_ENABLED || expression == currentEyeExpression) return;

  switch (expression) {
    case EyeExpression::CENTER:
      eyeDisplay.createChar(0, CENTER_TOP);
      eyeDisplay.createChar(1, CENTER_BOTTOM);
      showEyeCharacters(0, 1);
      break;
    case EyeExpression::LEFT:
      showEyeCharacters(2, 3);
      break;
    case EyeExpression::RIGHT:
      showEyeCharacters(4, 5);
      break;
    case EyeExpression::BLINK:
      showEyeCharacters(6, 7);
      break;
    case EyeExpression::HAPPY:
      eyeDisplay.createChar(0, HAPPY_TOP);
      eyeDisplay.createChar(1, HAPPY_BOTTOM);
      showEyeCharacters(0, 1);
      break;
    case EyeExpression::SURPRISED:
      eyeDisplay.createChar(0, SURPRISED_TOP);
      eyeDisplay.createChar(1, SURPRISED_BOTTOM);
      showEyeCharacters(0, 1);
      break;
    case EyeExpression::SLEEP:
      eyeDisplay.createChar(0, SLEEP_TOP);
      eyeDisplay.createChar(1, SLEEP_BOTTOM);
      showEyeCharacters(0, 1);
      break;
  }
  currentEyeExpression = expression;
}
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
void loop() {
  server.handleClient();
  updateWifiDiagnostics();
  updateServoSequence();
  updatePencilSensors();
  updateRfid();
  updateSession();
  updateCountdownDisplay();
  updateEyeDisplay();
  updateShake();
  handleServoCalibration();
  delay(2);
}

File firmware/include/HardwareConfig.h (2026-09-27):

#pragma once

namespace HardwareConfig {
// Keep false until the unloaded servo calibration in HARDWARE_TRAINING.md is complete.
constexpr bool SERVO_ENABLED = false;
constexpr bool SERVO_CALIBRATION_MODE = false;
// One-shot bench test: sweep 90 -> 0 -> 90 three times, then detach.
// Never enable while the servo is mechanically constrained.
constexpr bool SERVO_CYCLE_TEST_MODE = false;
constexpr int SERVO_CYCLE_ORIGINAL_ANGLE = 90;
constexpr int SERVO_CYCLE_CCW_ANGLE = 0;
constexpr unsigned int SERVO_CYCLE_REPETITIONS = 3;
constexpr unsigned int SERVO_CYCLE_STEP_DELAY_MS = 15;
constexpr unsigned int SERVO_CYCLE_HOLD_MS = 500;
// Direct-position test using the team's physical labels:
// physical 270 -> 180 -> 270 maps to servo commands 90 -> 0 -> 90.
constexpr bool SERVO_SWIFT_TEST_MODE = false;
constexpr int SERVO_SWIFT_270_COMMAND = 90;
constexpr int SERVO_SWIFT_180_COMMAND = 0;
constexpr unsigned int SERVO_SWIFT_HOLD_MS = 700;
constexpr int SERVO_CALIBRATION_START_ANGLE = 90;
constexpr int SERVO_UNLOCK_ANGLE = 30; // Placeholder: replace after calibration.
constexpr int SERVO_LOCK_ANGLE = 90;   // Placeholder: replace after calibration.
constexpr int SERVO_MIN_PULSE_US = 500;
constexpr int SERVO_MAX_PULSE_US = 2400;

// Local-network calibration page. Disable this before deployment if desired.
constexpr bool DEVELOPER_TOOLS_ENABLED = true;
constexpr int SERVO_WEB_MIN_ANGLE = 0;
constexpr int SERVO_WEB_MAX_ANGLE = 180;
constexpr unsigned int SERVO_WEB_MAX_REPETITIONS = 10;
constexpr unsigned int SERVO_WEB_MIN_HOLD_MS = 100;
constexpr unsigned int SERVO_WEB_MAX_HOLD_MS = 5000;

// The claws are fixed. Each sensor measures whether the pencil is resting above it.
// Replace these placeholder thresholds using the training readings.
constexpr bool PENCIL_PRESENT_WHEN_DISTANCE_LESS = true;
constexpr unsigned int LEFT_PENCIL_THRESHOLD_MM = 80;
constexpr unsigned int RIGHT_PENCIL_THRESHOLD_MM = 80;
constexpr unsigned long PENCIL_DEBOUNCE_MS = 350;
constexpr unsigned int SENSOR_TIMEOUT_MS = 100;
constexpr unsigned int SENSOR_PERIOD_MS = 50;
constexpr bool SENSOR_DIAGNOSTICS = true;

// Demo fallback: RFID is bypassed and the two shells are selected on the website.
constexpr bool RFID_ENABLED = false;
constexpr char MANUAL_SHELL_1_UID[] = "SHELL1";
constexpr char MANUAL_SHELL_2_UID[] = "SHELL2";
constexpr unsigned long MANUAL_SHELL_1_DEFAULT_SECONDS = 15UL * 60UL;
constexpr unsigned long MANUAL_SHELL_2_DEFAULT_SECONDS = 30UL * 60UL;

constexpr char ACCESS_POINT_NAME[] = "Focus-Lock";
constexpr unsigned long MAX_SESSION_SECONDS = 8UL * 60UL * 60UL;
constexpr unsigned long DEFAULT_SHELL_SECONDS = 25UL * 60UL;
constexpr unsigned int MAX_SHELLS = 12;

constexpr bool TM1637_ENABLED = true;
constexpr unsigned char TM1637_BRIGHTNESS = 5;

// Common I2C-backpack address. Change to 0x3F if an I2C scan finds that address.
constexpr bool LCD1602_ENABLED = true;
constexpr unsigned char LCD1602_ADDRESS = 0x27;

// Assumes a passive buzzer. Set false until the buzzer type and wiring are verified.
constexpr bool BUZZER_ENABLED = false;
constexpr bool BUZZER_TEST_MODE = false;
constexpr unsigned char BUZZER_PWM_CHANNEL = 7;

// The second SG90 sways the crab only while actively studying.
constexpr bool SHAKE_SERVO_ENABLED = false;
constexpr int SHAKE_CENTER_ANGLE = 90;
constexpr int SHAKE_LEFT_ANGLE = 75;
constexpr int SHAKE_RIGHT_ANGLE = 105;
constexpr unsigned long SHAKE_INTERVAL_MS = 700;
} // namespace HardwareConfig

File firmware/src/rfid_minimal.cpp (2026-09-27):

#include <Arduino.h>
#include <MFRC522.h>
#include <SPI.h>

namespace TestPins {
constexpr int RFID_CS = 5;
constexpr int RFID_SCK = 18;
constexpr int RFID_MOSI = 23;
constexpr int RFID_MISO = 19;
constexpr int RFID_RST = 27;
} // namespace TestPins

MFRC522 testReader(TestPins::RFID_CS, TestPins::RFID_RST);
unsigned long lastScanAt = 0;
unsigned long lastWaitingReportAt = 0;

String testUid() {
  String uid;
  for (byte index = 0; index < testReader.uid.size; ++index) {
    if (testReader.uid.uidByte[index] < 0x10) uid += '0';
    uid += String(testReader.uid.uidByte[index], HEX);
  }
  uid.toUpperCase();
  return uid;
}

void printDigitalDiagnostics() {
  Serial.print("MINIMAL_RFID version_reads=");
  for (byte index = 0; index < 8; ++index) {
    if (index) Serial.print(',');
    Serial.printf("%02X", testReader.PCD_ReadRegister(MFRC522::VersionReg));
    delay(2);
  }
  Serial.println();

  testReader.PCD_SetAntennaGain(testReader.RxGain_min);
  const byte minimumGain = testReader.PCD_GetAntennaGain();
  testReader.PCD_SetAntennaGain(testReader.RxGain_max);
  const byte maximumGain = testReader.PCD_GetAntennaGain();
  const byte txControl = testReader.PCD_ReadRegister(MFRC522::TxControlReg);

  Serial.printf(
    "MINIMAL_RFID spi_hz=%lu gain_00=%02X gain_70=%02X round_trip=%s tx_control=%02X antenna_bits=%s self_test=NOT_RUN\n",
    static_cast<unsigned long>(MFRC522_SPICLOCK),
    minimumGain,
    maximumGain,
    minimumGain == testReader.RxGain_min && maximumGain == testReader.RxGain_max ? "PASS" : "FAIL",
    txControl,
    (txControl & 0x03) == 0x03 ? "ON" : "OFF");
}

void setup() {
  Serial.begin(115200);
  delay(500);
  Serial.println("\nMINIMAL_RFID boot: RC522 only; all other hardware disabled.");

  SPI.begin(TestPins::RFID_SCK, TestPins::RFID_MISO, TestPins::RFID_MOSI, TestPins::RFID_CS);
  testReader.PCD_Init();
  printDigitalDiagnostics();
}

void loop() {
  const unsigned long now = millis();
  if (now - lastScanAt < 250) return;
  lastScanAt = now;

  byte atqa[2];
  byte atqaSize = sizeof(atqa);
  const MFRC522::StatusCode wakeStatus = testReader.PICC_WakeupA(atqa, &atqaSize);
  if (wakeStatus != MFRC522::STATUS_OK && wakeStatus != MFRC522::STATUS_COLLISION) {
    if (now - lastWaitingReportAt >= 1000) {
      lastWaitingReportAt = now;
      Serial.printf("MINIMAL_RFID scan_status=%u (%s)\n",
        static_cast<unsigned int>(wakeStatus),
        testReader.GetStatusCodeName(wakeStatus));
    }
    return;
  }

  Serial.printf("MINIMAL_RFID atqa=%02X%02X wake_status=%u\n",
    atqa[0], atqa[1], static_cast<unsigned int>(wakeStatus));
  if (!testReader.PICC_ReadCardSerial()) {
    Serial.println("MINIMAL_RFID ATQA received but UID selection failed.");
    return;
  }

  Serial.printf("MINIMAL_RFID UID=%s size=%u sak=%02X\n",
    testUid().c_str(), testReader.uid.size, testReader.uid.sak);
  testReader.PICC_HaltA();
  testReader.PCD_StopCrypto1();
}

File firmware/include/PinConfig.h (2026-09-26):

#pragma once

// Classic 30-pin ESP32 / ESP-WROOM-32 DevKit V1 pin allocation.
namespace Pins {
constexpr int RFID_CS = 5;
constexpr int RFID_SCK = 18;
constexpr int RFID_MOSI = 23;
constexpr int RFID_MISO = 19;
constexpr int RFID_RST = 27;

constexpr int I2C_SDA = 21;
constexpr int I2C_SCL = 22;
constexpr int LEFT_PENCIL_XSHUT = 32;
constexpr int RIGHT_PENCIL_XSHUT = 33;

constexpr int DISPLAY_CLK = 14;
constexpr int DISPLAY_DIO = 13;

constexpr int LOCK_SERVO = 26;
constexpr int SHAKE_SERVO = 25;
constexpr int BUZZER = 17;
} // namespace Pins

namespace I2cAddresses {
constexpr unsigned char LEFT_PENCIL = 0x30;
constexpr unsigned char RIGHT_PENCIL = 0x31;
} // namespace I2cAddresses

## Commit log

2026-09-26 Add safe ESP32 firmware base and hardware training
2026-09-26 Implement complete Focus Lock interaction flow
2026-09-27 Add servo calibration tools and connection diagnostics
2026-09-27 stl files
    [body_print.STL, claw_arm.STL, drawer_base.STL]
2026-09-27 Add files via upload
    full complete stls
    [base_stand.STL, big_shell.STL, small_shell.STL]
